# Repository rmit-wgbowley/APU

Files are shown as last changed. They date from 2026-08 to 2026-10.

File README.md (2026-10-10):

<!--
Colors:
FFFFFF - Pure white
e01e37 - Bold crimson-red 

Hello,
I enjoyed working with others for once, and being able
to have my own architecturally defined piece in the 
car is pretty damn cool.

- William Bowley, 2026-08-17

P.S: 
Thanks for downloading the APU repository `▽`ʃ♡ — but please be safe with high-voltage boards :)

-->

<div align="center">
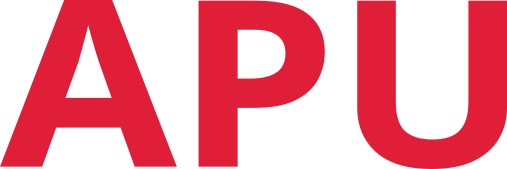
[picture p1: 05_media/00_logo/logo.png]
APU Logo
  

  A proposed low-voltage grounded APU for FSAE-A vehicles <br>
</div>

### Overview

The APU is a proposed power architecture that allows the tractive battery, while connected, to feed the low-voltage grounded (LVG) system via an isolated LLC converter, using the LVG battery as a line buffer. 
The LVG battery also allows for standby mode while the tractive battery is disconnected.

```
Traction battery (600 V) → APU-LLC (12 V) → APU-Battery (12 V) → LVG Systems (12 V)
```

### Objectives

```
- [/] Support a `400-600 V` input range from the tractive battery.
- [/] Support up to `300 W (DC)` continuous loads and `800 W (DC)` peak transient loading.
- [/] Reach an asymptote temperature under `70°C` with passive cooling.
- [ ] Validate the APU architecture and generate performance curves.
- [ ] Pass the EMC/EMI requirements and pass the 2027 Formula SAE rules inspection.
```

> *(Note). `[ ]` Not started. `[/]` In progress. `[x]` Complete.*

---

### Magnetic Passives

> *(Ordered). The transformer and inductor formers and cores are on-hand, with litz wire yet to be ordered.*

#### Transformer

The transformer used for this design has an `N87` core with a `glass fibre` coil former and snap-on `ABS` insulation rings. 
The turns ratio is `21:1:1`, with `0.125 mm × 64` litz wire used on the primary with a PTFE sleeve across 3 layers of 14 turns each. 
The secondary and tertiary windings each have a single layer of 2 turns with `0.125 mm × 650` litz wire. Each layer is wrapped in `0.1 mm`
polyimide tape.

<div align="center">
  <table>
    <tr>
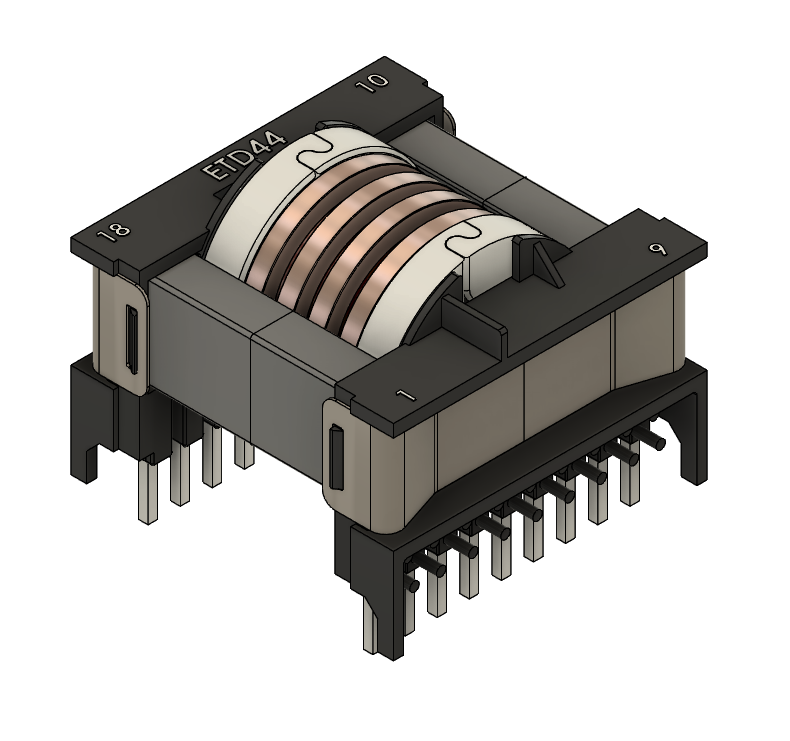
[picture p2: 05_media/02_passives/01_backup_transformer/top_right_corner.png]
Transformer 2 Side
      <td></td>
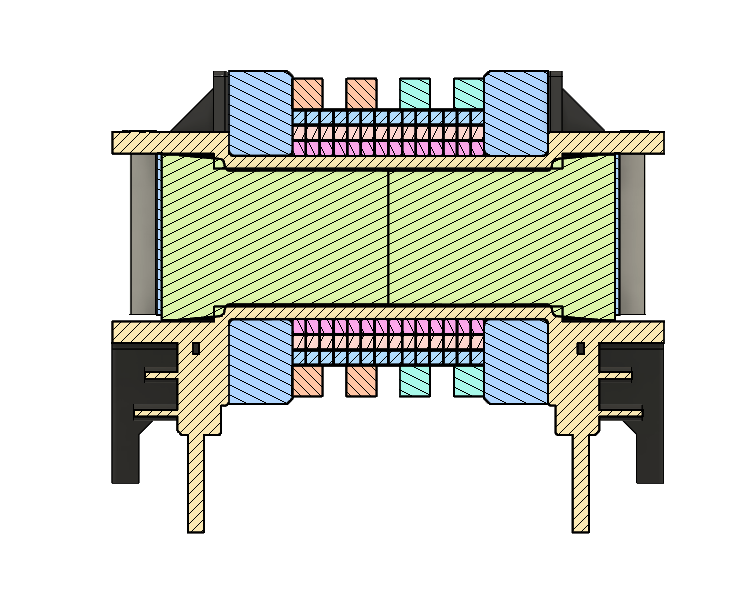
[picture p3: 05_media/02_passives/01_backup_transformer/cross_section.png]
Transformer 2 Cross Section
      <td></td>
    </tr>
  </table>
</div>

#### External Inductor

The external inductor used for this design has an `N87` core with a `glass fibre` coil former, and uses the same litz wire (`0.125 mm × 64`) as the transformer primary. The number of turns within the inductor is dependent on the transformer's characteristics.

<div align="center">
  <table>
    <tr>
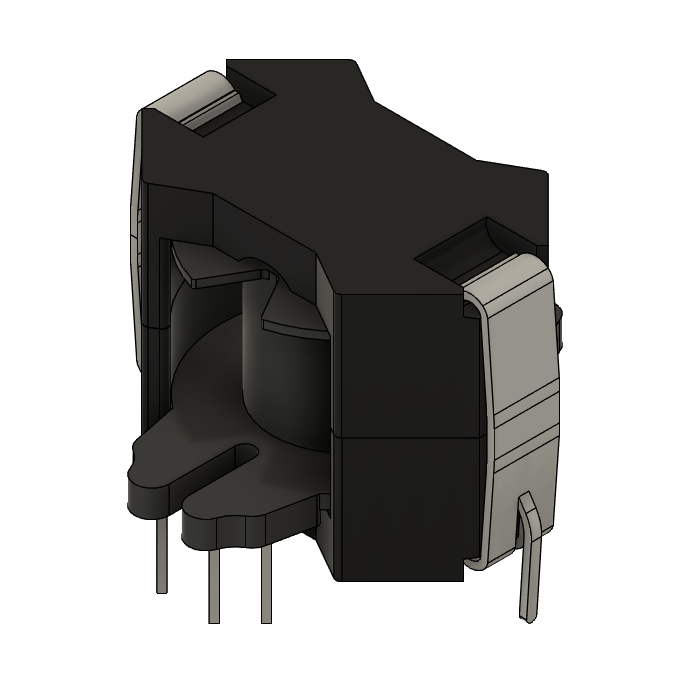
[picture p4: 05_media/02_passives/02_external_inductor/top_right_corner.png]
External Inductor Side
      <td></td>
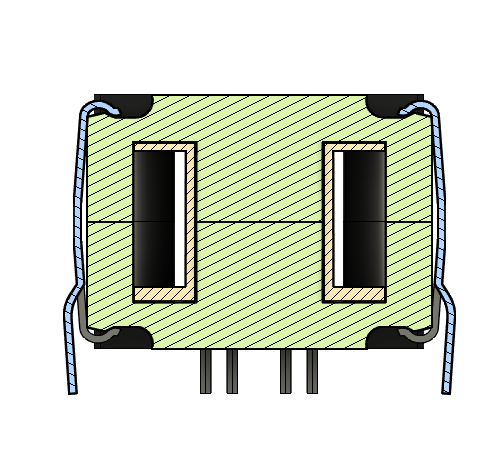
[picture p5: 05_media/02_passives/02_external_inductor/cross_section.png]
External Inductor Cross Section
      <td></td>
    </tr>
  </table>
</div>

See the [`02_passives`](./02_passives/readme.md) for implementation details.

---

### LLC Boards

#### LLC High Voltage Side (LLC-HVS)

> *(Work in progress). This board is currently being designed in altium*

This board uses the `UCC25600DRG4` resonant mode controller to control the LLC half-bridge via the `ISO7720DWVR` for digital isolation. The half-bridge itself is built around the `IR2214SSPBF` with two `E3M0075120K` FETs. This board also contains the resonant network and the primary side of the transformer.

```
Resonant Controller (UCC25600DRG4)
              ↓
Digital Isolator (ISO7720DWVR)
              ↓
Half Bridge Driver (IR2214SSPBF) → FETs (E3M0075120K)
              ↓
Resonant Network (Series Capacitor, Inductor & Transformer Primary)
```

#### LLC Low Voltage Side (LLC-LVS)

> *(Dependency). This board is currently paused until the LLC-HVS is finished.*

See the [`03_boards`](./03_boards/readme.md) for implementation details.

---

### APU Battery & External Charging Interface

> *(Dependency). The APU battery is dependent on the implementation of the LLC-HVS and LLC-LVS.*

The proposed battery type for the APU battery is a soft-case LiPo using cells in series to achieve the required 12 V. 
LiPo batteries also tend to have a high C-rating, hence they can buffer high line transients.

---

### APU Packaging & Integration

> *(Dependency). The APU packaging is dependent on all of the above.* <br>

The proposed integration is to package the LLC converter above the APU battery, with the converter ultimately sitting next to the 
APU-BI and APU-EBC boards, with a separation plane between the battery.

---

### Documentation

Each section of the repo is self-documenting. <br>
For internal documentation, credits, and contributors, refer to [`00_docs`](./00_docs/readme.md).

---

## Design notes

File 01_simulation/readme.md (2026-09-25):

### Overview

This folder contains the simulation workflows used within this project, including finite element analysis, 
analytical modelling, and circuit-net (SPICE) simulations.

---

### 00_analytical

This folder contains analytical models for exploring design variables and building system intuition at medium fidelity but extremely fast.

```
- First Harmonic Approximation (FHA)
- Transfer Gain vs Input Voltage
- Winding Loading
```

For detailed documentation, refer to [`00_analytical/readme.md`](00_analytical/readme.md).

---

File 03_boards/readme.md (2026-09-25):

### 03_boards

This folder contains the board designs for the LLC converter, external battery charger interface, and battery connector interface.

---

### [00_LLC_HVS](./00_llc_hvs/readme.md)

LLC High Voltage Side

*(TBD) — Work in progress*

---

### [01_LLC_LVS](./01_llc_lvs/readme.md)

LLC Low Voltage Side

*(TBD) — Work in progress*

---

### 02_APU_EBC

Auxiliary Power Unit External Battery Charger

*(TBD) — Work in progress*

---

### 03_APU_BI

Auxiliary Power Unit Battery Interface

*(TBD) — Work in progress*

---

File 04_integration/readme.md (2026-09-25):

### 04_integration

This folder contains the packaging for the LLC converter, battery interface components and the battery.

*(TBD) — Work in progress*

---

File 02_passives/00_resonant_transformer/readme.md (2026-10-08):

### 00_resonant_transformer

Both resonant transformers use an `N87` core with a `glass fibre` coil former and snap-on `ABS` insulation rings. The turns ratio is `21:1:1`, with `0.125 mm × 64` litz wire used on the primary with PTFE sleeve across 3 layers of 14 turns each. The secondary and tertiary windings each have a single layer of 2 turns with `0.125 mm × 650` litz wire. Each layer is wrapped in `0.1 mm` polyimide tape.

#### Primary Transformer

<div align="center">
  <table>
    <tr>
      <td>Transformer 2 Side</td>
      <td>Transformer 2 Cross Section</td>
    </tr>
  </table>
</div>

The primary transformer uses the `B66364A2000X000` core and `B66363G0000X187` coil former. 
This transformer has a smaller cross-sectional area than the backup transformer, which means it saturates at a lower current.

---

#### Backup Transformer

<div align="center">
  <table>
    <tr>
      <td>Transformer 2 Side</td>
      <td>Transformer 2 Cross Section</td>
    </tr>
  </table>
</div>

The backup transformer uses the `B66366A2000X000` core and `B66365G0000X187` coil former. 
This transformer has a larger cross-sectional area than the primary, which means it saturates at a higher current.

---

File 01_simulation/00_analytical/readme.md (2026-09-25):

### 00_analytical

This folder contains analytical models to explore design variables at medium fidelity but extremely fast.

> Do not assume the resulting design variables are suitable for fabrication or real-world use without further analysis.

#### First Harmonic Approximation (FHA)

This analytical model is written in `Python` and uses `picounits` for parameter loading and unit validation. It models the resonant circuit two-port model described in application note `AN2450` by ST,
and also in a `2024 RMIT` paper, though they use different models. The ST FHA model was used in this implementation.

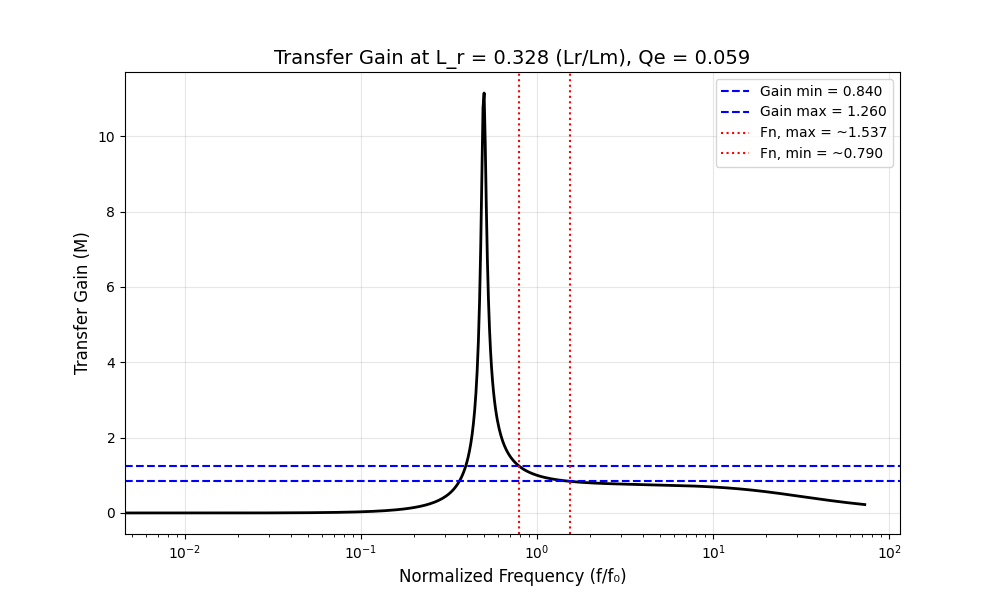
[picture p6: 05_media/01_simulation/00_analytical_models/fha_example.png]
FHA_Example
<div align="center">
<p><em>Figure 1: First Harmonic Approximation output showing transfer gain (linear) vs frequency (log).</em></p></div>

> Model: [`first_harmonic_approximation`](./00_first_harmonic_approximation/main.py)  
> Parameters: [`parameters.uiv`](./00_first_harmonic_approximation/parameters.uiv)

---

#### Transfer Gain vs Input Voltage

This analytical model is written in `Python` and uses `picounits` for parameter loading and unit validation. It models the 
transfer gain vs input voltage using the equations described in application note `AN2450` by ST.

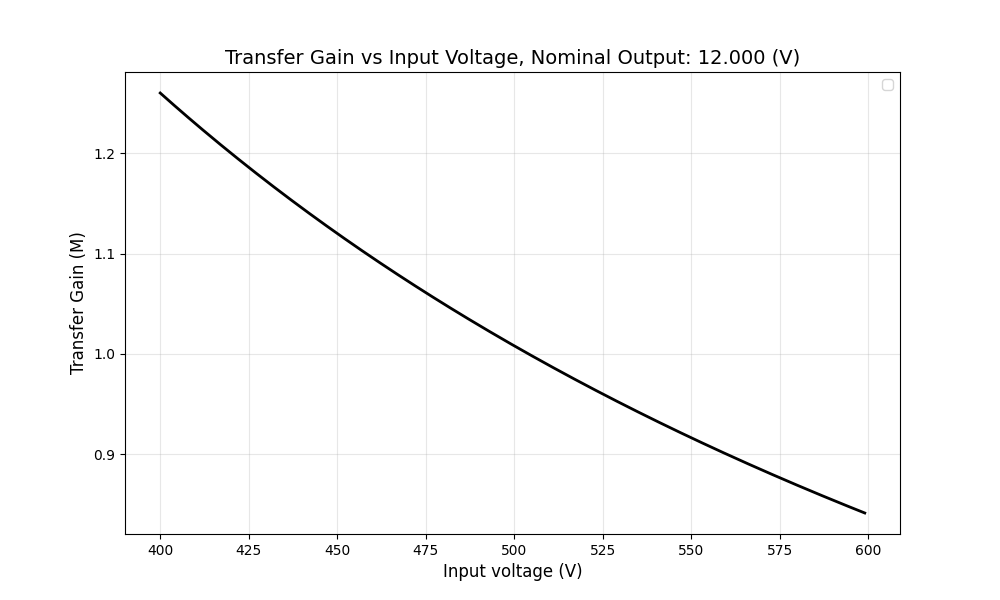
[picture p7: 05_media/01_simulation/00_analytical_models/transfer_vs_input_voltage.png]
Transfer gain vs input voltage
<div align="center">
<p><em>Figure 2: Analytical model showing transfer gain (linear) vs input voltage (linear).</em></p></div>

> Model: [`transfer_gain`](./01_transfer_gain/main.py)  
> Parameters: [`parameters.uiv`]`(./01_transfer_gain/parameters.uiv)

---

#### Winding Loading

This analytical model is written in `Python` and uses `picounits` for parameter loading and unit validation. It calculates primary and secondary wire diameters across a range of current densities at a target power level, helping to inform winding design for the LLC converter.

> Wire diameters shown are bulk equivalents. Litz wire or multi-strand conductors are required in practice due to skin effect at high frequencies.

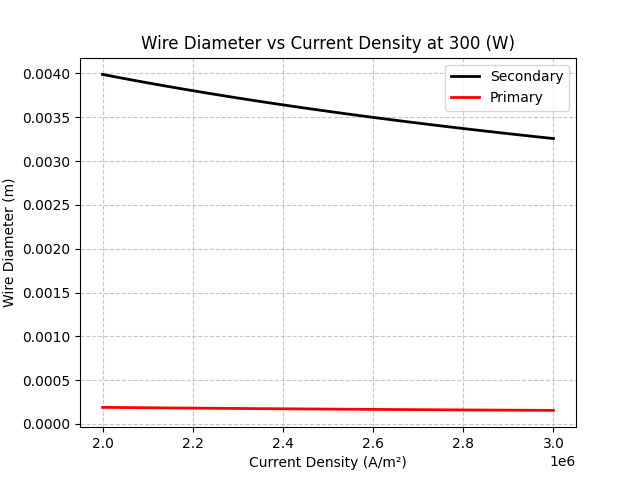
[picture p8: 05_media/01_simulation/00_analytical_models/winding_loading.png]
Winding loading analysis
<div align="center">
<p><em>Figure 3: Primary and secondary wire diameter vs current density at a fixed target power.</em></p></div>

> Model: [`winding_load`](./02_winding_loading/main.py)  
> Parameters: [`parameters.uiv`](./02_winding_load/parameters.uiv)

---

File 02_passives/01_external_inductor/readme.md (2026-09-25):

### 01_external_inductor

The external inductor uses the `B65811J0400A087` core with a `B65812N1012D001` coil former and `0.125 mm × 64` litz wire used on the primary with a PTFE sleeve.

<div align="center">
  <table>
    <tr>
      <td>External Inductor Side</td>
      <td>External Inductor Cross Section</td>
    </tr>
  </table>
</div>

---

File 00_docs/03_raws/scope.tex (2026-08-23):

\documentclass[12pt,a4paper]{article}
\usepackage[utf8]{inputenc}
\usepackage{geometry}
\geometry{margin=1in}
\usepackage{graphicx}
\usepackage{float}        
\usepackage{titlesec}
\usepackage{tocloft}
\usepackage{hyperref}
\usepackage{fancyhdr}
\usepackage{textcomp} 
\usepackage{listings}

\lstset{
    frame=single,
    basicstyle={\small\ttfamily},
    breaklines=true,
    columns=flexible,
    literate={->}{{ $\rightarrow$} }2
             {<-}{{$\leftarrow$} }2
             {down}{{$\downarrow$}}4
}

\hypersetup{
    colorlinks=true,
    linkcolor=blue,
    urlcolor=blue,
}

% Customize section formatting
\titleformat{\section}{\large\bfseries}{\thesection}{1em}{}
\titleformat{\subsection}{\normalsize\bfseries}{\thesubsection}{1em}{}

% Header and footer setup
\pagestyle{fancy}
\fancyhf{}

% Left header
\fancyhead[L]{\textbf{Project Scope}}

% Right header
\fancyhead[R]{\textbf{LVG-APU}}

% Page number in footer
\fancyfoot[C]{\thepage}

\begin{document}

% Title Page
\begin{center}
    {\Large \textbf{Low Voltage Grounded Auxiliary Power Unit}} \\[0.3cm]
    {\large AUTO1931 | Project Scope Report} \\[0.2cm]
    {\today}\\[0.5cm]
\end{center}

\vfill

% ========== Overview ==========
\section*{Overview}

Formula SAE Electric (FSAE-E) vehicles have two main voltage levels: one is the tractive system, which is up to 600 VDC, and the
other is the low-voltage grounded (LVG) system, which is up to 60 VDC. RMIT Motorsports (RMIT-M) uses a 600 V tractive system and a 13.2 V LVG system.
The tractive system is supplied by the tractive battery, which contains 143 lithium cells. Similarly, the LVG system is supplied by a lithium battery.
However, it is a commercial unit certified by the FAA for aircraft!?

\vspace{0.5cm}

The low-voltage grounded auxiliary power unit (APU) is a proposed design to feed the LVG system from the tractive system while the tractive battery
is installed in the vehicle. This APU would also have to be able to supply power while the tractive battery is disconnected from the vehicle, so it is
also proposed that the LVG battery is scoped within the component. Hence the name ``auxiliary power unit,'' as it provides the power required (LVG battery)
during setup to close the contactor (similar to cranking amps), which is required to power the isolated (split grounds) DC-to-DC converter.

\vspace{0.5cm}

Later, the LVG battery buffers the line voltage during heavy loading, reducing the converter's required power output range. This also allows for the
implementation of isolated external power input for the LVG battery, which is proposed to be an IP-rated (ingress protection) USB-C input to remove the 
dependency of another charging apparatus within the vehicle supporting equipment. This allows for a design with high self-reliance. At worst, it could be a USB-C laptop charger!

\vspace{0.5cm}

\begin{quote}
  \textbf{Supporting:}
    The impedance (L, R) between the LVG battery and the DC-to-DC converter is important due to the coupling (mutual influence) between them when supplying the 
    line voltage across a wide range of power draws and rates of change of that draw. Hence the inclusion.
\end{quote}

\newpage

% ========== System Specifications ==========
\section{System Specification}

The APU as an intermediate component between the tractive system and the LVG system, is designed from the interfaces inwards (within reason). Hence the first specification 
is the input voltage range, which can be derived from the voltage cycle of a single lithium battery. The average rating is \~3.7 V, the maximum is \~4.2 V, and the minimum is \~3.0 V, with 
approximately 143 cells within the tractive battery. The input voltage range is \~600--400 V, whereas the output, for simplicity, will be \~12 V.

\vspace{0.5cm}

This leads into the power requirements, which is quite a complex question to answer in any capacity other than building and measuring the R27 LVG system. However, the R26 design can be used as a 
reference for this. According to an approximate current draw diagram, the LVG system should draw 15.9 A continuously with a peak of 66 A (Appendix 1a). This translates to a power output range of 
\~190--790 W.

\begin{quote}
  \textbf{Supporting:} 
  It should be noted that the exact technique used to approximate these values is unknown, and a few items are poorly defined.
\end{quote}

The two topologies that were assessed were a flyback converter and an LLC converter. A flyback works by storing energy in the magnetic field of a transformer and then releasing it in pulses. This allows 
for the output voltage to be controlled at a high level by the duration of the repeating ``on'' pulse (PWM). The LLC converter uses a switching configuration to generate a square wave, and then that wave enters 
a resonant tank, which is simply a capacitor and inductor in series or parallel. This tank produces a sinusoidal wave and, like the flyback, has a transformer which then outputs the energy (at a high level). 
The output can then be controlled through the switching signal by varying frequency and timing.

\vspace{0.5cm}

From those two topologies, the main cornerstone for selecting one is the power output required rather than specifically implementation complexity. From this perspective, the LLC is preferable as it often has better 
scaling capabilities. Since it is not storing energy in pulses, the maximum output range can be much higher. The LLC also has two different methods of controlling the output, each of which has different power ranges. 
This allows for more implementation options on top (half-bridge vs. full-bridge). Hence, the LLC topology was chosen.

\vspace{0.5cm}

Therefore, the LLC converter will need to be sized for the approximate nominal power draw and acceptable current density within the LLC transformer. Using a rule-of-thumb model (Appendix 1b) based on current density and 
wire diameter, a series of graphs relating current density and wire diameter were generated. From that and the power range inherited by the R26 documentation and R\&D report about future driverless integration, a 
final requirement of 300 W was decided. It should allow up to 33\% output buffer based on R26 continuous draw, while also not making the transformer impractical to design.

\begin{quote}
  \textbf{Rationale:} 
  At a current density (current per cross-sectional area) of $\sim 2.6 \, {A/mm}^2$ on the secondary with a ratio from an RMIT-M paper of 21:1, a bulk (solid) diameter of 3.5 mm is required, which is reasonable. 
  It falls within the natural cooling range at 2.0--3.0 ${A/mm}^2$ and insulation class A, which is abundant.
\end{quote}

% ========== Literature and Design Review ==========
\section{Literature and Design Review}

The search performed during this scoping phase did not identify the APU as an established discrete system architecture. Therefore, the review focuses on the isolated
LLC converter, which forms the centre of gravity of the proposed architecture.

\begin{lstlisting}
Traction battery (600 V)
        down
LVG-APU Input Interface
-----------------------------------------------------------------
Isolated LLC resonant DC/DC (300 W Target) <- (We're Here)
        down
LV battery buffer (Energy Buffer) <- Isolated Charger (External Input)
-----------------------------------------------------------------
LVG-APU Output Interface
        down
LV vehicle systems (12 V) (200 W Estimate)
\end{lstlisting}

\begin{quote}
  \textbf{Important:} 
    We're here! Given the initial scoping of ``600V to 12V Isolated DC/DC Converter \& LV Integration,'' the above analysis had to be done to decompose and reconstruct the 
    system for clear design and objectives.
\end{quote}

\subsection{A Customised Low-voltage Power Supply for a Formula SAE Electric Racing Vehicle}

This paper is relevant as it describes the design and implementation of a 240 W LLC converter for FSAE and was completed in 2024 by RMIT-M students for a capstone.
This design implements the LLC converter as a single package consisting of five different boards following a modular approach. The switching method is a half-bridge
and gate driver, which is then controlled by a resonant controller. The switches were 1200 V silicon carbide FETs, and the frequency range was 100--200 kHz with a
21:1 turn ratio within the transformer and series capacitor. The output is then filtered by a synchronous rectifier.

\begin{figure}[H]
    \centering
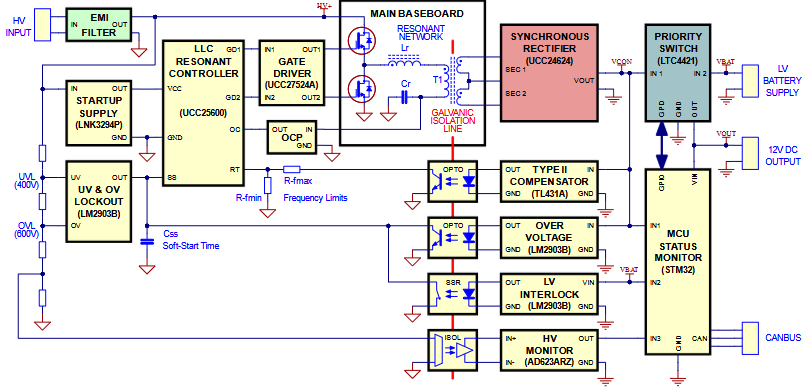
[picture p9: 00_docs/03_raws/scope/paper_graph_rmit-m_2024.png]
    
    \caption{Block diagram of the LLC converter from the paper}
\end{figure}

\subsection{DCDC: An open source credit card sized DC/DC converter to convert up to 600 V to 24 V in an energy-, cost- and space-efficient way}

This repository (repo) contains a high-voltage DC/DC converter designed for the FSAE German competition and, according to the repo, passed 
scrutineering twice and has been operating without issues for over 6 months. The maximum output power is 750 W for 60 seconds and 500 W continuous. The
design input voltage range is 200 to 600 V and has an output range of 24 V, with the ability to customize it for 12 V to 48 V outputs. The design
is quite small at only 167 grams and has a volume of 0.208 L. 

\begin{figure}[H]
    \centering
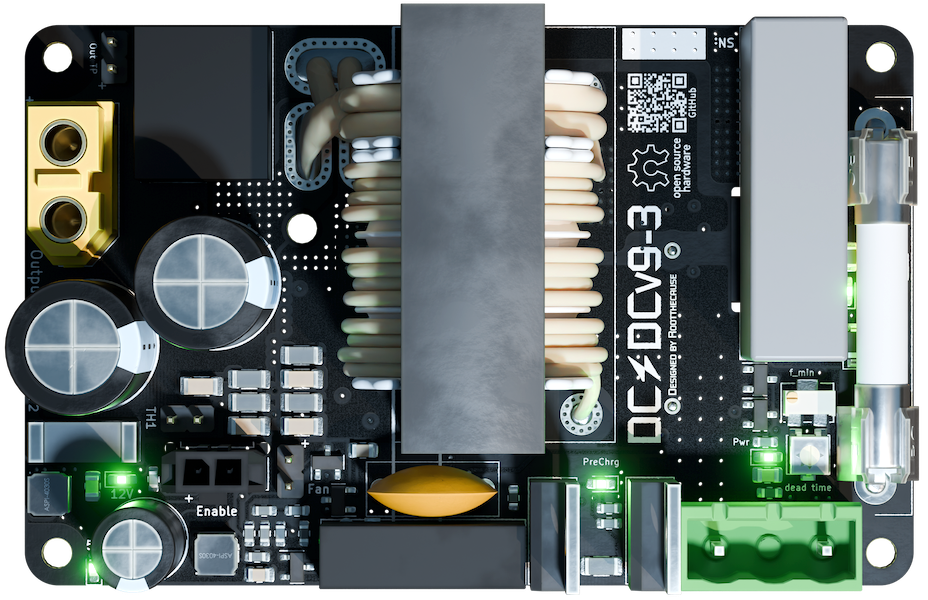
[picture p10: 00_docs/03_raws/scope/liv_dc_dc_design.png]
    
    \caption{DC/DC PCB design populated with components}
\end{figure}

According to the repo, the design features a solid-state precharge circuit, active rectification, and under- and over-voltage protection. It also
has over-current protection and, lastly, HV and LV fuses. The repo notes that the dynamic operating range is 90 to 200 kHz to ``ensure high efficiency for various loads''
and ``good EMI compliance due to \ldots LLC topology.''

\subsection{Interpretation}

The two reviewed designs demonstrate that isolated LLC conversion is an established approach for high-voltage to low-voltage conversion. Both operate over an input 
range overlapping with the 400--600 V requirement, while their power ratings of 240 W and 600 W provide precedent for the 300 W target.

\vspace{0.5cm}

However, neither design directly establishes the proposed APU architecture. The reviewed systems seem to treat the DC/DC converter as the power-supply 
component in abstract rather than as a coupled system. Therefore, these designs will be used as precedent for the LLC subsystem rather than as a complete implementation
reference.

\vspace{0.5cm}

The 2024 RMIT-M paper will be the primary reference for the LLC converter design and implementation, as it shows the design methodology for designing the system using
first harmonic approximation (FHA) and detailed transformer construction methods. The modular design approach is quite elegant from a testing perspective. Hence, a similar approach
will be adopted for this implementation.

% ========== Conceptual Design ==========
\section{Conceptual Design}

The proposed design for the APU is to begin with the LLC converter as two independent boards, which are then mechanically and electrically connected
via the high-frequency transformer. This reflects the natural system boundaries between the high and low voltage sides while also improving the ability to perform
sub-circuit testing following a similar approach to the 2024 RMIT-M paper.

\vspace{0.5cm}

\hbox{\large{High Level Topology:}}
\begin{lstlisting}
Interface (Undecided Connector) 
LLC-HV - Tractive battery input (400-600V domain) (Unknown EMI)
-----------------------------------------------------------------
EMI filter (Common-mode chokes) (Shunt Capacitors)
        down
Half Bridge Mosfets <- Half bridge Driver IC <- LLC Controller <- Optocoupler
        down
Resonant Tank Circuit
-----------------------------------------------------------------
High Frequency Transformer (Primary) (400-600 HF AC)

=============================================
Ferrite Core (Magnetic & Structural Coupling)
=============================================

LLC-LV - High Frequency transformer (Secondary) (12V AC) (Unknown Ripple)
-----------------------------------------------------------------
Synchronous Rectifier -> Status MCU (STM32) <- Optocoupler
        down
Integrated battery (12 V) (Undecided Capacity) <- Isolated Charger
-----------------------------------------------------------------
LV-Interface (Undecided Connector) (12V Domain) (Unknown EMI)
\end{lstlisting}

\vspace{0.5cm}

This design follows the 2027 Formula SAE rules draft. It allows for a GLV system to operate independently of the tractive battery (EV.4.4.1). It also
is galvanically isolated via magnetic coupling and optocouplers for signal routing (EV.7.5.1). It also avoids the same-board tractive system and GLV rule (EV.7.5.7) 
with two independent boards. However, for the optocouplers on the LLC-HV board, the area will be clearly marked and have a clearance distance of 3.0 mm and a creepage distance under
conformal coating of 4.0 mm when operating at 300--600 VDC (EV 7.5.7).

\vspace{0.5cm}

The implementation plan is firstly to use planar finite element analysis to design the ferrite core transformer, and then design the LLC-HV board. The transformer will then be characterized,
and an appropriate capacitor will be chosen. Then the LLC-HV board and transformer will be tested together with a dummy load. After that, the LLC-LV board will be made based on those testing
results. The LLC-HV and LLC-LV boards will then be tested together and characterized, with the transient response helping to determine the capability of the APU-integrated battery. After which,
the whole system will be packaged together as the LVG-APU and tested for EMI compliance, etc.

\vspace{0.5cm}

%========== Project Management ==========
\section{Project Management}

The project will follow a waterfall-like project cycle, with each deliverable design leading into the next (within reason). The project deliverables consist of the LLC-HV and LLC-LV boards, the 
transformer, the LVG battery, and finally the APU package around those components.

\begin{figure}[H]
    \centering
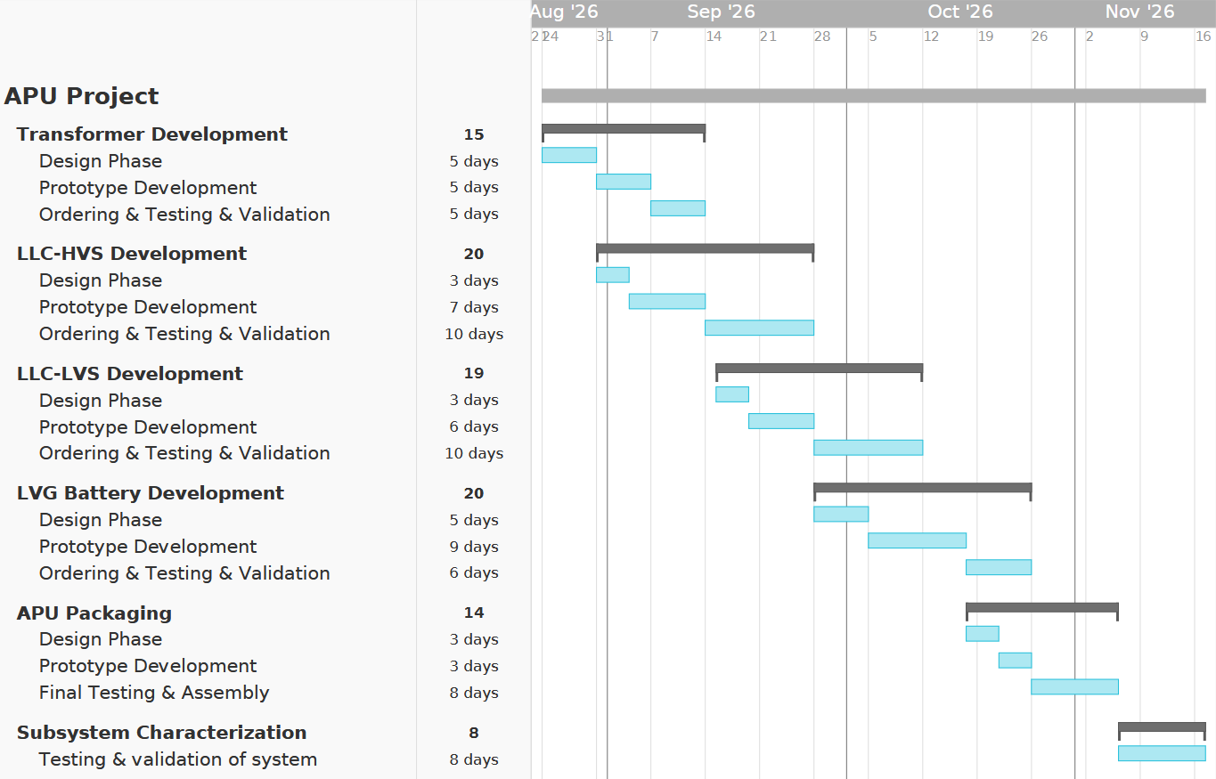
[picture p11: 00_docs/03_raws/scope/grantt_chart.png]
    
    \caption{Gantt chart showing the project timeline and deliverables}
\end{figure}

\begin{quote}
  \textbf{Rationale:} 
  The deliverables overlap, as the design phase of each defines enough information to begin development of the next. Given the timeframe of this project, 
  the execution has to be concurrent. The ``Ordering \& Testing \& Validation'' blocks are due to the transient nature of procurement and safety reviews.
\end{quote}

\vspace{0.5cm}

Similar to the project scope phase, the implementation work will be hosted on GitHub with code, documentation, and reference implementation within the repo.
Engineering notes and design rationale will be within the repo issues. The repo follows the information scheme for issues (Appendix 2).

% ========== Conclusion ==========
\section{Conclusion}

The LVG-APU for the R27 vehicle will be a first iteration of a new power system within the vehicle. The design arises from the architectural requirements 
of the LVG system, and the requirements formed arise from the current implementation and reference designs described in the literature review. The system consists of five deliverables:
the LLC-HV and LLC-LV boards, the transformer, the LVG battery, and the APU packaging.

% ========== References ==========
\section{References}

\begin{enumerate}
    \item RMIT Motorsports, ``A Customised Low-voltage Power Supply for a Formula SAE Electric Racing Vehicle'', Capstone Project, RMIT University, 2024.
    \item RMIT Motorsports, ``Innovative Actuation Systems for a Driverless Formula SAE Racing Car'', Capstone Project, RMIT University, 2021.
    \item liv (rootthecause), ``DCDC: An open source credit card sized DC/DC converter to convert up to 600 V to 24 V in an energy-, cost- and space-efficient way'',
    GitHub repository. Available: https://github.com/liv-instruments/dcdc
    \item Formula SAE Rules, ``2027 Formula SAE Rules'', SAE International, Draft, 2026.
\end{enumerate}

% ========== Appendices ==========
\section{Appendices}

\subsection{Appendix 1a: R26 LVG System Current Draw Estimation}

\begin{figure}[H]
    \centering
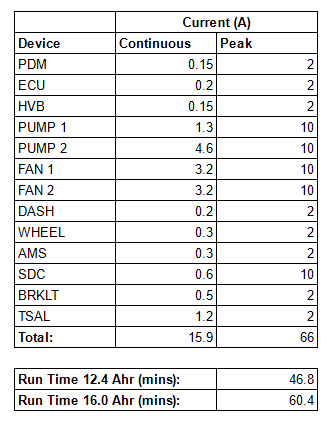
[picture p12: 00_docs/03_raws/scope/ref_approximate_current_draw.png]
    
    \caption{R26 LVG System Current Estimation}
\end{figure}

\newpage

\subsection{Appendix 1b: Current Density and Wire Diameter Model}

\begin{lstlisting}
# Calculate wire diameter across current density range at target power
current_density = parameters.transformer.range.min_current_density
while current_density <= parameters.transformer.range.max_current_density:
    # Calculates the wire diameter based on target current & current density
    inner_term = 4 * target_current / (pi * current_density)
    secondary_wire_diameter = inner_term ** 0.5
    primary_wire_diameter = secondary_wire_diameter / parameters.transformer.turns

    # Saves parameters as raw values (kA/m^2, mm, mm)
    current_density_axis.append(current_density.stripped * 10 ** -3)
    primary_wire_diameter_axis.append(primary_wire_diameter.stripped * 10 ** 3)
    secondary_wire_diameter_axis.append(secondary_wire_diameter.stripped * 10 ** 3)

    # Updates current density for next iteration
    current_density += parameters.numerics.current_density
\end{lstlisting}

\subsection{Appendix 2: GitHub Issue Labelling Scheme}

\begin{lstlisting}
LX -> Documentation and project structure
L0 -> Review and analysis of reference designs
L1 -> System level design, topology and interfaces
L2 -> Detailed design & prototyping
L3 -> Testing & Validation of prototype
DS -> De-scoped Feature, De-scoped Analysis
AC -> Architectural Change
\end{lstlisting}

\end{document}

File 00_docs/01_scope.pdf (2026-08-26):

Project Scope | LVG-APU

## Low Voltage Grounded Auxiliary Power Unit

### AUTO1931 — Project Scope Report

August 26, 2026

### Overview

Formula SAE Electric (FSAE-E) vehicles have two main voltage levels: one is the tractive system, which is up to 600 VDC, and the other is the low-voltage grounded (LVG) system, which is up to 60 VDC. RMIT Motorsports (RMIT-M) uses a 600 V tractive system and a 13.2 V LVG system. The tractive system is supplied by the tractive battery, which contains 143 lithium cells. Similarly, the LVG system is supplied by a lithium battery. However, it is a commercial unit certified by the FAA for aircraft!?

The low-voltage grounded auxiliary power unit (APU) is a proposed design to feed the LVG system from the tractive system while the tractive battery is installed in the vehicle. This APU would also have to be able to supply power while the tractive battery is disconnected from the vehicle, so it is also proposed that the LVG battery is scoped within the component. Hence the name “auxiliary power unit,” as it provides the power required (LVG battery) during setup to close the contactor (similar to cranking amps), which is required to power the isolated (split grounds) DC-to-DC converter.

Later, the LVG battery buffers the line voltage during heavy loading, reducing the converter’s required power output range. This also allows for the implementation of isolated external power input for the LVG battery, which is proposed to be an IP-rated (ingress protection) USB-C input to remove the dependency of another charging apparatus within the vehicle supporting equipment. This allows for a design with high self-reliance. At worst, it could be a USB-C laptop charger!

Supporting: The impedance (L, R) between the LVG battery and the DCto-DC converter is important due to the coupling (mutual influence) between them when supplying the line voltage across a wide range of power draws and rates of change of that draw. Hence the inclusion.

### 1 System Specification

The APU as an intermediate component between the tractive system and the LVG system, is designed from the interfaces inwards (within reason). Hence the first specification is the input voltage range, which can be derived from the voltage cycle of a single lithium battery. The average rating is ˜3.7 V, the maximum is ˜4.2 V, and the minimum is ˜3.0 V, with approximately 143 cells within the tractive battery. The input voltage range is ˜600–400 V, whereas the output, for simplicity, will be ˜12 V.

This leads into the power requirements, which is quite a complex question to answer in any capacity other than building and measuring the R27 LVG system. However, the R26 design can be used as a reference for this. According to an approximate current draw diagram, the LVG system should draw 15.9 A continuously with a peak of 66 A (Appendix 1a). This translates to a power output range of ˜190–790 W.

Supporting: It should be noted that the exact technique used to approximate these values is unknown, and a few items are poorly defined.

The two topologies that were assessed were a flyback converter and an LLC converter. A flyback works by storing energy in the magnetic field of a transformer and then releasing it in pulses. This allows for the output voltage to be controlled at a high level by the duration of the repeating “on” pulse (PWM). The LLC converter uses a switching configuration to generate a square wave, and then that wave enters a resonant tank, which is simply a capacitor and inductor in series or parallel. This tank produces a sinusoidal wave and, like the flyback, has a transformer which then outputs the energy (at a high level). The output can then be controlled through the switching signal by varying frequency and timing.

From those two topologies, the main cornerstone for selecting one is the power output required rather than specifically implementation complexity. From this perspective, the LLC is preferable as it often has better scaling capabilities. Since it is not storing energy in pulses, the maximum output range can be much higher. The LLC also has two different methods of controlling the output, each of which has different power ranges. This allows for more implementation options on top (half-bridge vs. full-bridge). Hence, the LLC topology was chosen.

Therefore, the LLC converter will need to be sized for the approximate nominal power draw and acceptable current density within the LLC transformer. Using a rule-of-thumb model (Appendix 1b) based on current density and wire diameter, a series of graphs relating current density and wire diameter were generated. From that and the power range inherited by the R26 documentation and R&D report about future driverless integration, a final requirement of 300 W was decided. It should allow up to 33% output buffer based on R26 continuous draw, while also not making the transformer impractical to design.

Rationale: At a current density (current per cross-sectional area) of ∼
2.6 A/mm²
on the secondary with a ratio from an RMIT-M paper of 21:1, a bulk (solid) diameter of 3.5 mm is required, which is reasonable. It falls within the natural cooling range at 2.0–3.0 A/mm²
and insulation class A,
which is abundant.

### 2 Literature and Design Review

The search performed during this scoping phase did not identify the APU as an established discrete system architecture. Therefore, the review focuses on the isolated LLC converter, which forms the centre of gravity of the proposed architecture.

Traction battery (600 V)
↓
LVG-APU Input Interface
-----------------------------------------------------------------Isolated LLC resonant DC/DC (300 W Target) ← (We’re Here)
↓
LV battery buffer (Energy Buffer) ← Isolated Charger (External Input) -----------------------------------------------------------------LVG-APU Output Interface
↓
LV vehicle systems (12 V) (200 W Estimate)

Important: We’re here! Given the initial scoping of “600V to 12V Isolated DC/DC Converter & LV Integration,” the above analysis had to be done to decompose and reconstruct the system for clear design and objectives.

### 2.1 A Customised Low-voltage Power Supply for a Formula SAE Electric

Racing Vehicle

This paper is relevant as it describes the design and implementation of a 240 W LLC converter for FSAE and was completed in 2024 by RMIT-M students for a capstone. This design implements the LLC converter as a single package consisting of five different boards following a modular approach. The switching method is a half-bridge and gate driver, which is then controlled by a resonant controller. The switches were 1200 V silicon carbide FETs, and the frequency range was 100–200 kHz with a 21:1 turn ratio within the transformer and series capacitor. The output is then filtered by a synchronous rectifier.

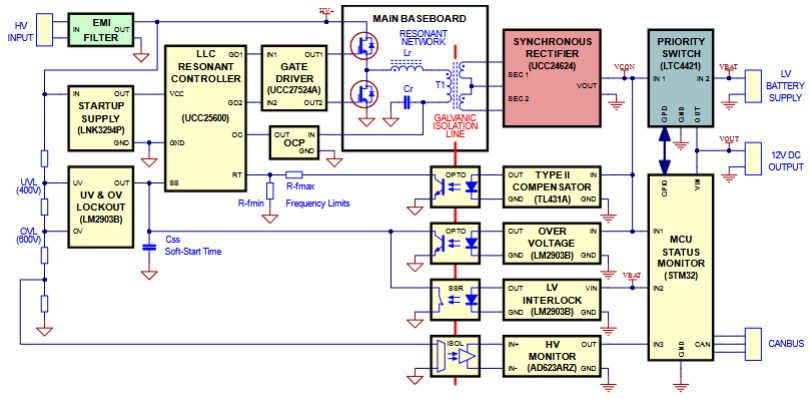
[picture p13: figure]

Figure 1: Block diagram of the LLC converter from the paper

### 2.2 DCDC: An open source credit card sized DC/DC converter to convert

up to 600 V to 24 V in an energy-, cost- and space-efficient way

This repository (repo) contains a high-voltage DC/DC converter designed for the FSAE German competition and, according to the repo, passed scrutineering twice and has been operating without issues for over 6 months. The maximum output power is 750 W for 60 seconds and 500 W continuous. The design input voltage range is 200 to 600 V and has an output range of 24 V, with the ability to customize it for 12 V to 48 V outputs. The design is quite small at only 167 grams and has a volume of 0.208 L.

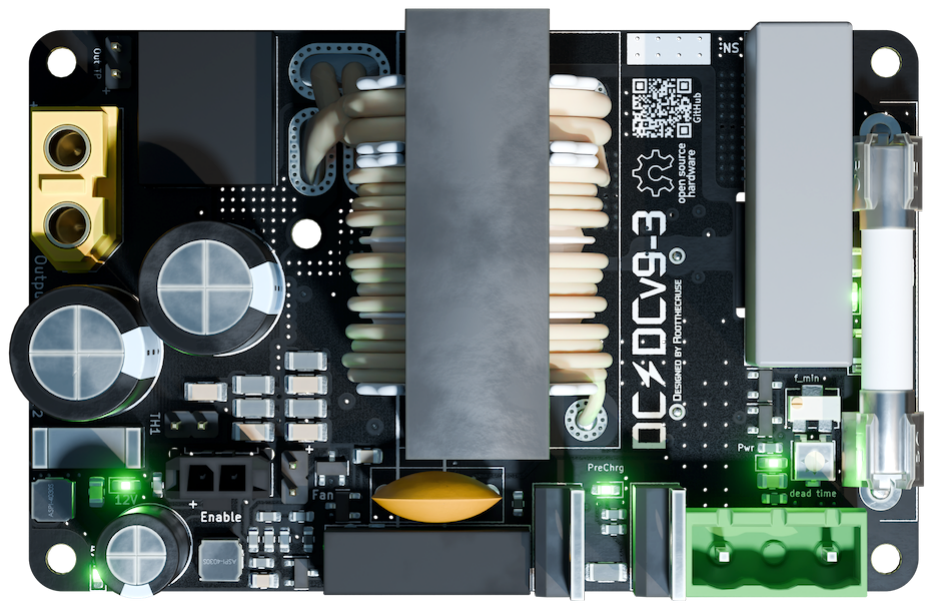
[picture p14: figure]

Figure 2: DC/DC PCB design populated with components

According to the repo, the design features a solid-state precharge circuit, active rectification, and under- and over-voltage protection. It also has over-current protection and, lastly, HV and LV fuses. The repo notes that the dynamic operating range is 90 to 200 kHz to “ensure high efficiency for various loads” and “good EMI compliance due to . . . LLC topology.”

### 2.3 Interpretation

The two reviewed designs demonstrate that isolated LLC conversion is an established approach for high-voltage to low-voltage conversion. Both operate over an input range overlapping with the 400–600 V requirement, while their power ratings of 240 W and 600 W provide precedent for the 300 W target.

However, neither design directly establishes the proposed APU architecture. The reviewed systems seem to treat the DC/DC converter as the power-supply component in abstract rather than as a coupled system. Therefore, these designs will be used as precedent for the LLC subsystem rather than as a complete implementation reference.

The 2024 RMIT-M paper will be the primary reference for the LLC converter design and implementation, as it shows the design methodology for designing the system using first harmonic approximation (FHA) and detailed transformer construction methods. The modular design approach is quite elegant from a testing perspective. Hence, a similar approach will be adopted for this implementation.

### 3 Conceptual Design

The proposed design for the APU is to begin with the LLC converter as two independent boards, which are then mechanically and electrically connected via the high-frequency transformer. This reflects the natural system boundaries between the high and low voltage sides while also improving the ability to perform sub-circuit testing following a similar approach to the 2024 RMIT-M paper.

### High Level Topology:

Interface (Undecided Connector)
LLC-HV - Tractive battery input (400-600V domain) (Unknown EMI) -----------------------------------------------------------------
EMI filter (Common-mode chokes) (Shunt Capacitors)
↓
Half Bridge Mosfets ← Half bridge Driver IC ← LLC Controller ← Optocoupler ↓
Resonant Tank Circuit
High Frequency Transformer (Primary) (400-600 HF AC)

=============================================
Ferrite Core (Magnetic & Structural Coupling) =============================================

LLC-LV - High Frequency transformer (Secondary) (12V AC) (Unknown Ripple) -----------------------------------------------------------------Synchronous Rectifier → Status MCU (STM32) ← Optocoupler
↓
Integrated battery (12 V) (Undecided Capacity) ← Isolated Charger -----------------------------------------------------------------LV-Interface (Undecided Connector) (12V Domain) (Unknown EMI)

This design follows the 2027 Formula SAE rules draft. It allows for a GLV system to operate independently of the tractive battery (EV.4.4.1). It also is galvanically isolated via magnetic coupling and optocouplers for signal routing (EV.7.5.1). It also avoids the same-board tractive system and GLV rule (EV.7.5.7) with two independent boards. However, for the optocouplers on the LLC-HV board, the area will be clearly marked and have a clearance distance of 3.0 mm and a creepage distance under conformal coating of 4.0 mm when operating at 300–600 VDC (EV 7.5.7).

The implementation plan is firstly to use planar finite element analysis to design the ferrite core transformer, and then design the LLC-HV board. The transformer will then be characterized, and an appropriate capacitor will be chosen. Then the LLC-HV board and transformer will be tested together with a dummy load. After that, the LLC-LV board will be made based on those testing results. The LLC-HV and LLC-LV boards will then be tested together and characterized, with the transient response helping to determine the capability of the APU-integrated battery. After which, the whole system will be packaged together as the LVG-APU and tested for EMI compliance, etc.

### 4 Project Management

The project will follow a waterfall-like project cycle, with each deliverable design leading into the next (within reason). The project deliverables consist of the LLC-HV and LLC-LV boards, the transformer, the LVG battery, and finally the APU package around those components.


Figure 3: Gantt chart showing the project timeline and deliverables

Rationale: The deliverables overlap, as the design phase of each defines enough information to begin development of the next. Given the timeframe of this project, the execution has to be concurrent. The “Ordering & Testing & Validation” blocks are due to the transient nature of procurement and safety reviews.

Similar to the project scope phase, the implementation work will be hosted on GitHub with code, documentation, and reference implementation within the repo. Engineering notes and design rationale will be within the repo issues. The repo follows the information scheme for issues (Appendix 2).

### 5 Conclusion

The LVG-APU for the R27 vehicle will be a first iteration of a new power system within the vehicle. The design arises from the architectural requirements of the LVG system, and the requirements formed arise from the current implementation and reference designs described in the literature review. The system consists of five deliverables: the LLC-HV and LLC-LV boards, the transformer, the LVG battery, and the APU packaging.

### 6 References

1. RMIT Motorsports, “A Customised Low-voltage Power Supply for a Formula SAE Electric Racing Vehicle”, Capstone Project, RMIT University, 2024.
2. RMIT Motorsports, “Innovative Actuation Systems for a Driverless Formula SAE Racing Car”, Capstone Project, RMIT University, 2021.
3. liv (rootthecause), “DCDC: An open source credit card sized DC/DC converter to convert up to 600 V to 24 V in an energy-, cost- and space-efficient way”, GitHub repository. Available: https://github.com/liv-instruments/dcdc
4. Formula SAE Rules, “2027 Formula SAE Rules”, SAE International, Draft, 2026.

### 7 Appendices

### 7.1 Appendix 1a: R26 LVG System Current Draw Estimation

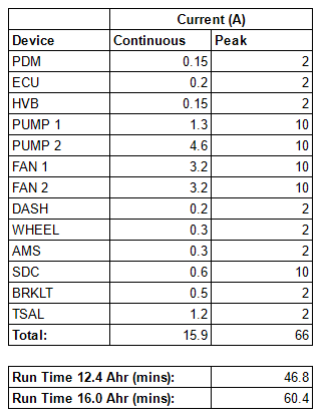
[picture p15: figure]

Figure 4: R26 LVG System Current Estimation

### 7.2 Appendix 1b: Current Density and Wire Diameter Model

# Calculate wire diameter across current density range at target power current_density = parameters.transformer.range.min_current_density

while current_density <= parameters.transformer.range.max_current_density: # Calculates the wire diameter based on target current & current density inner_term = 4 * target_current / (pi * current_density) secondary_wire_diameter = inner_term ** 0.5
primary_wire_diameter = secondary_wire_diameter / parameters.transformer. turns

# Saves parameters as raw values (kA/m^2, mm, mm) current_density_axis.append(current_density.stripped * 10 ** -3) primary_wire_diameter_axis.append(primary_wire_diameter.stripped * 10 ** 3) secondary_wire_diameter_axis.append(secondary_wire_diameter.stripped * 10 ** 3)

# Updates current density for next iteration

current_density += parameters.numerics.current_density

### 7.3 Appendix 2: GitHub Issue Labelling Scheme

LX | → Documentation and project structure
L0 | → Review and analysis of reference designs
L1 | → System level design, topology and interfaces
L2 | → Detailed design & prototyping
L3 | → Testing & Validation of prototype
DS | → De-scoped Feature, De-scoped Analysis
AC | → Architectural Change

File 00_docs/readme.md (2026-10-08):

### 00_docs

This README contains the series of deliverables and their associated write-ups. It also contains the internal resources, tags and application notes series.

---

#### [Scope](01_scope.pdf) — Project Scope

This document describes the scope of the project and outlines how the `LVG-APU` architecture was derived, 
along with the implementation plan.

---

#### Internal Resources

All internal documentation can be found within this repo's [`issues`](https://github.com/rmit-wgbowley/APU/issues).

#### Tags:

```
Project Progress:
----------------------------------------------------
LX -> Documentation and project structure
L0 -> Review and analysis of reference designs
L1 -> System level design, topology and interfaces
L2 -> Detailed design & prototyping
L3 -> Testing & validation of prototype
----------------------------------------------------
```

<br>

```
Miscellaneous:
----------------------------------------------------
DS  -> De-scoped feature, de-scoped analysis
AC  -> Architectural change
ES  -> Electrical systems
SD  -> System development / Architectural development
SIM -> Simulations & modelling
AN  -> Weekly application notes
----------------------------------------------------
```

#### Application Notes

```
0x0 = Week 0
0x1 = Week 1
0x2 = Week 2
0x3 = Week 3
0x4 = Week 4    <- Current State
0x5 = Week 5
0x6 = Week 6
0x7 = Week 7
0x8 = Week 8
0x9 = Week 9
0xA = Week 10
0xB = Week 11
0xC = Week 12
0xD = Week 13
0xE = Week 14
0xF = Week 15   <- Terminal State
```

> Check [`here`](https://github.com/rmit-wgbowley/APU/issues?q=is%3Aissue%20label%3AAN) to view the weekly application notes.

---

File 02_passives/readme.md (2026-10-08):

### 02_passives

#### [00_resonant_transformer](./00_resonant_transformer/readme.md) — Primary & Backup transformers

<div align="center">
  <table>
    <tr>
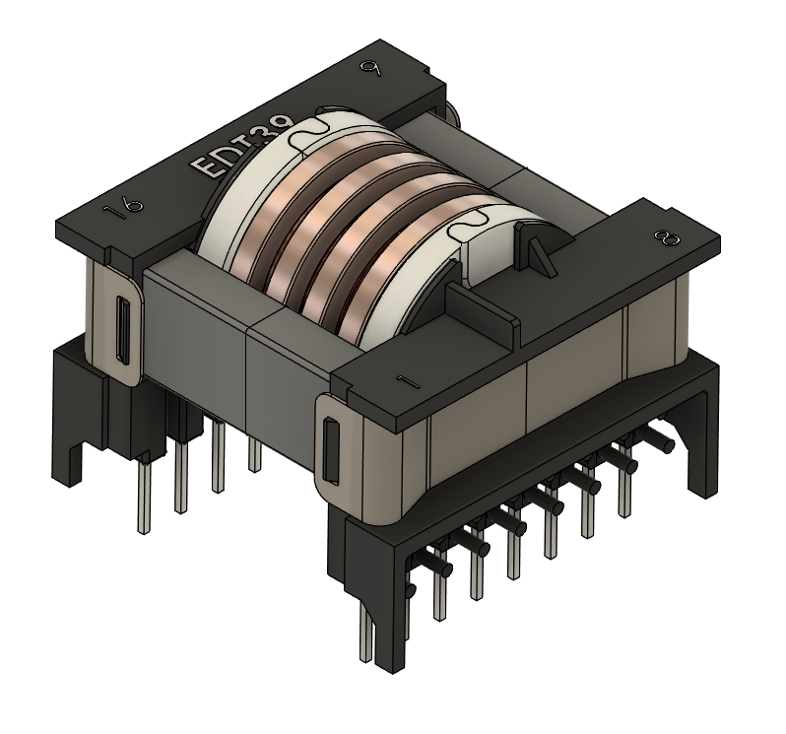
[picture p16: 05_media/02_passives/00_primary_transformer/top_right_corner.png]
Primary
      <td></td>
      <td>Backup</td>
    </tr>
    <tr>
      <td><em>Primary Transformer</em></td>
      <td><em>Backup Transformer</em></td>
    </tr>
  </table>
</div>

The resonant transformer forms part of the resonant tank circuit. 

---

#### [01_external_inductor](./01_external_inductor/readme.md) - External Inductor

<div align="center">
  <table>
    <tr>
      <td>External Inductor Side</td>
      <td>External Inductor Cross Section</td>
    </tr>
    <tr>
      <td><em>Top Right Side View</em></td>
      <td><em>Cross Sectional View</em></td>
    </tr>
  </table>
</div>

The external inductor allows for tuning of the resonant tank circuit via its self-inductance.

---

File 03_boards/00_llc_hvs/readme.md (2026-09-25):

### 00_llc_hvs

*(TBD) — Work in progress*

---

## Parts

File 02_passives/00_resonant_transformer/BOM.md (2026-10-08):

### Primary & Back-up Transformers — Bill of Materials (BOM)

| Status | Reference | Qty | Value | Footprint | Notes / Datasheet |
|---|---|-----|---|---|---|
| [-] | Core 1, Core 2 | 2 | B66364A2000X000 | TDK:ETD39_Core | Ferrite Core |
| [-] | Clamp 1 | 2 | B66364B1016T001 | TDK:ETD39_Clip | Coil Former Clip |
| [-] | Former 1 | 1 | B66363G0000X187 | TDK:ETD39_Former | Horizontal Coil Former |
| [x] | Core 3, Core 4 | 2 | B66366A2000X000 | TDK:ETD44_Core | Ferrite Core |
| [x] | Clamp 2 | 2 | B66366B1018T001 | TDK:ETD44_Clip | Coil Former Clip |
| [x] | Former 2 | 1 | B66365G0000X187 | TDK:ETD44_Former | Horizontal Coil Former |
| [ ] | Litz 2 | 1 | 64/38LITZ.125 | Wire:Litz_Rectangular | Primary Litz Wire |
| [ ] | Litz 1 | 1 | 650/42LITZ.125 | Wire:Litz_Rectangular | Secondary Litz Wire |
| [ ] | Sleeve 1 | 1 | STFE 20 CLR | N/A | PTFE Primary Sleeve | 
 
> *(Note). `[ ]` Not Ordered. `[-]` Not Required. `[x]` Ordered.*

---

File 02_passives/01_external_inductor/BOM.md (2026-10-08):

### External Inductor — Bill of Materials (BOM)

| Status | Reference | Qty | Value | Footprint | Notes / Datasheet |
|---|---|-----|---|---|---|
| [-] | Clamp | 2 | B65812A2203X000 | TDK:RM8_Clamp | Vertical Core Clamp | 
| [-] | Former  | 1 | B65812N1008D001 | TDK:RM8 | Vertical Coil Former |
| [-] | Core | 2 | B65811J0400A087 | TDK:RM8 | Vertical Ferrite Core Sections | 
| [-] | Sleeve 1 | 1 | STFE 20 CLR | N/A | PTFE Sleeve | 
| [ ] | Litz 2 | 1 | 64/38LITZ.125 | Wire:Litz_Rectangular | Litz Wire |

> *(Note). `[ ]` Not Ordered. `[-]` Not Required. `[x]` Ordered.*

---

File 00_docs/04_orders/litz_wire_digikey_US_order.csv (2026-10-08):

Index | Quantity | Part Number | Manufacturer Part Number | Description | Unit of Measure | Customer Reference | Available | Backorder | Unit Price | Extended Price USD
1 | 1 | 2328-650/42LITZ.125-ND | 650/42LITZ.125 | MAGNET WIRE 14 AWG 3 METER |  |  | 1 | 0 | 48.28000 | $48.28
2 | 1 | 2328-64/38LITZ.125-ND | 64/38LITZ.125 | MAGNET WIRE 20 AWG 11.9 METER |  |  | 1 | 0 | 37.60000 | $37.60

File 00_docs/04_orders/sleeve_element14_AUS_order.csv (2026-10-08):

Line No. | Order Code | RoHS Compliant? | Customer Reference No | Notes | Qty | Mfr Part No | Manufacturer Name | Manufacturer / Description | Availability | Unit Price (excl GST) ($) | Line Price (excl GST) ($) | Discount Price ($)
1 | 1191043 | RoHS: YES / PHTHALATES: YES |  |  | 1.0 | STFE 20 CLR | MULTICOMP PRO | MULTICOMP PRO Sleeving, Protective, PTFE (Polytetrafluoroethylene), Transparent, 0.97 mm, 5 m, 16.4 ft | 344 | 10.1700 | 10.17
 |  |  |  |  |  |  | Sub Total | $10.17
 |  |  |  |  |  |  | Goods Total | $10.17
 |  |  |  |  |  |  | Delivery | $0.00
 |  |  |  |  |  |  | GST | $1.02
 |  |  |  |  |  |  | Total | $11.19

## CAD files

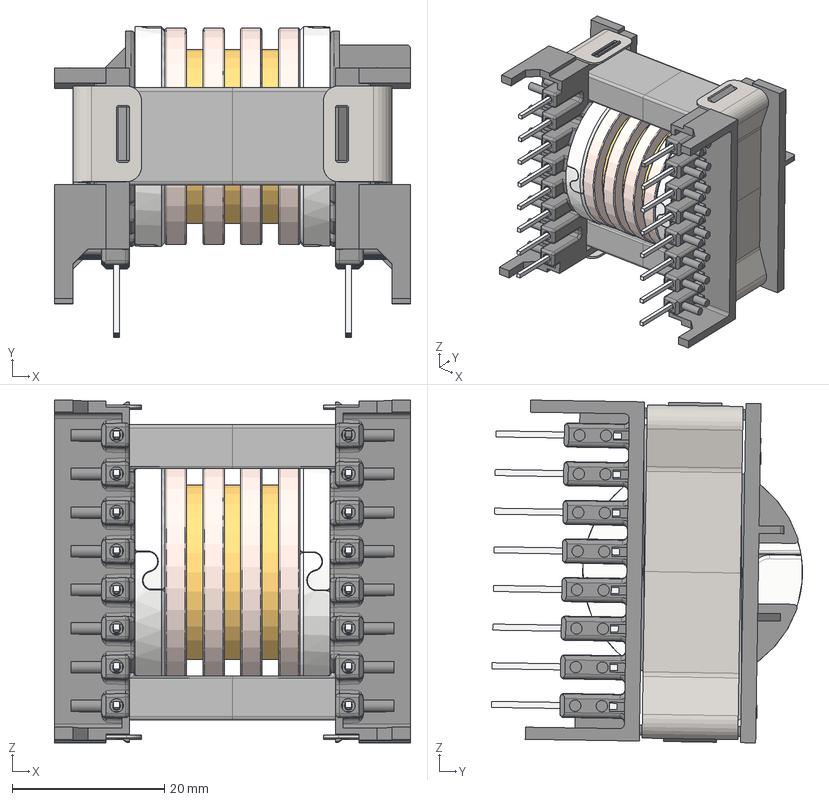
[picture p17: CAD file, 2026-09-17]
02_passives/00_resonant_transformer/03_mechanical/primary_transformer.step
46.8 x 40.9 x 45.1 mm
ETD39 Core x 2
ETD39 Yoke x 2
ETD39 Former
spacers x 2
Secondary x 2
tertiary x 2
tape_layer_3
layer_3
tape_layer_2
layer_2
tape_layer_1
layer_1

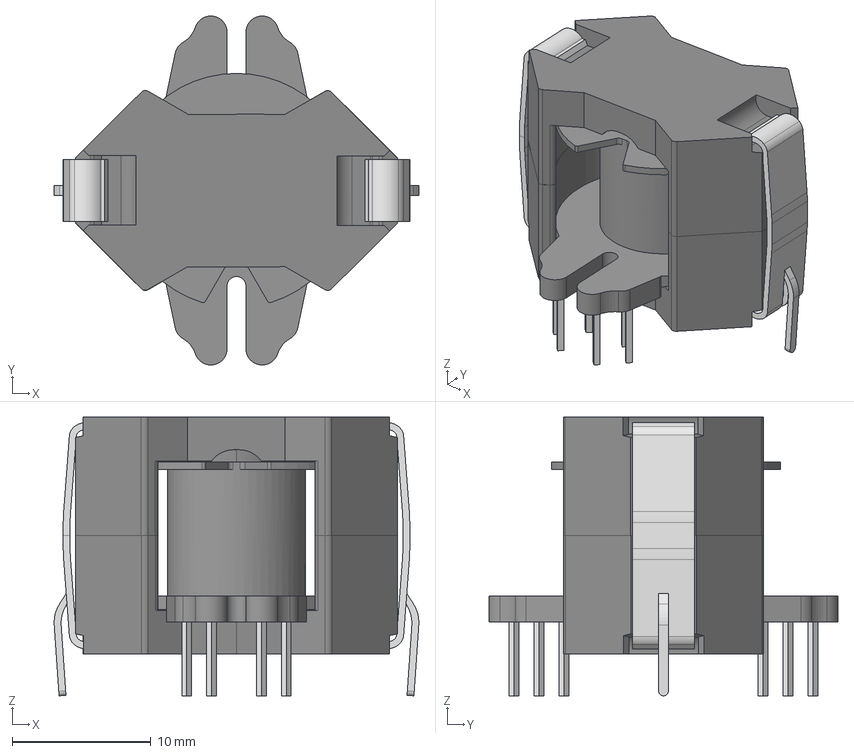
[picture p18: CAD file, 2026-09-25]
02_passives/01_external_inductor/03_mechanical/external_inductor.step
26.3 x 25.2 x 20.1 mm
RM8_bobbin
RM8_ferrite_B x 2
RM8_clip x 2
RM8_pin x 12

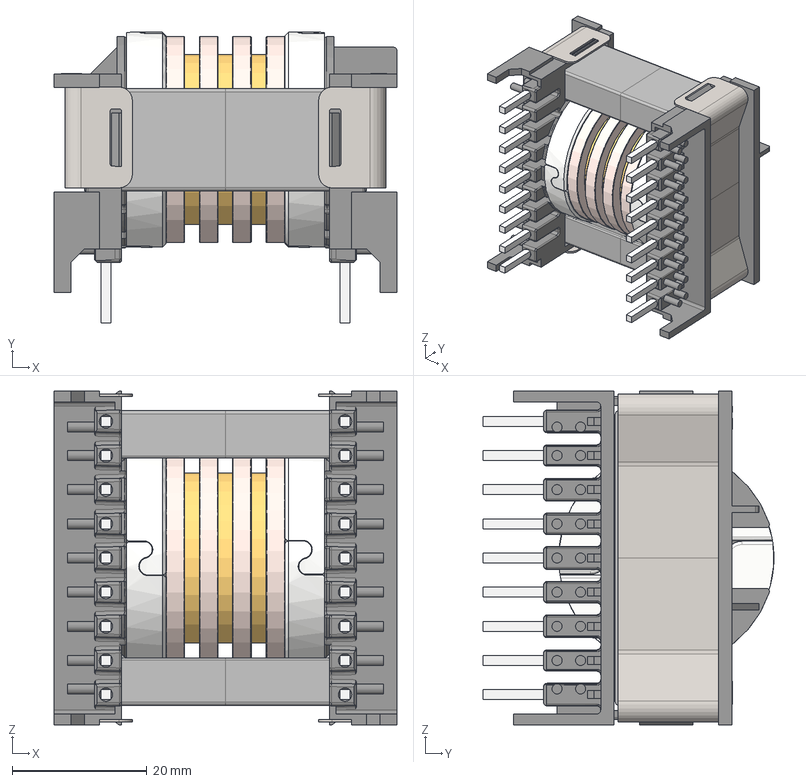
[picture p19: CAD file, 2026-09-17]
02_passives/00_resonant_transformer/03_mechanical/backup_transformer.step
51.0 x 43.2 x 49.6 mm
ETD44 Coilformer
ETD44 Core x 2
ETD44_Yoke x 2
spacers x 2
tape_layer_1
tape_layer_2
tape_layer_3
tertiary x 2
secondary x 2
layer_1
layer_2
layer_3

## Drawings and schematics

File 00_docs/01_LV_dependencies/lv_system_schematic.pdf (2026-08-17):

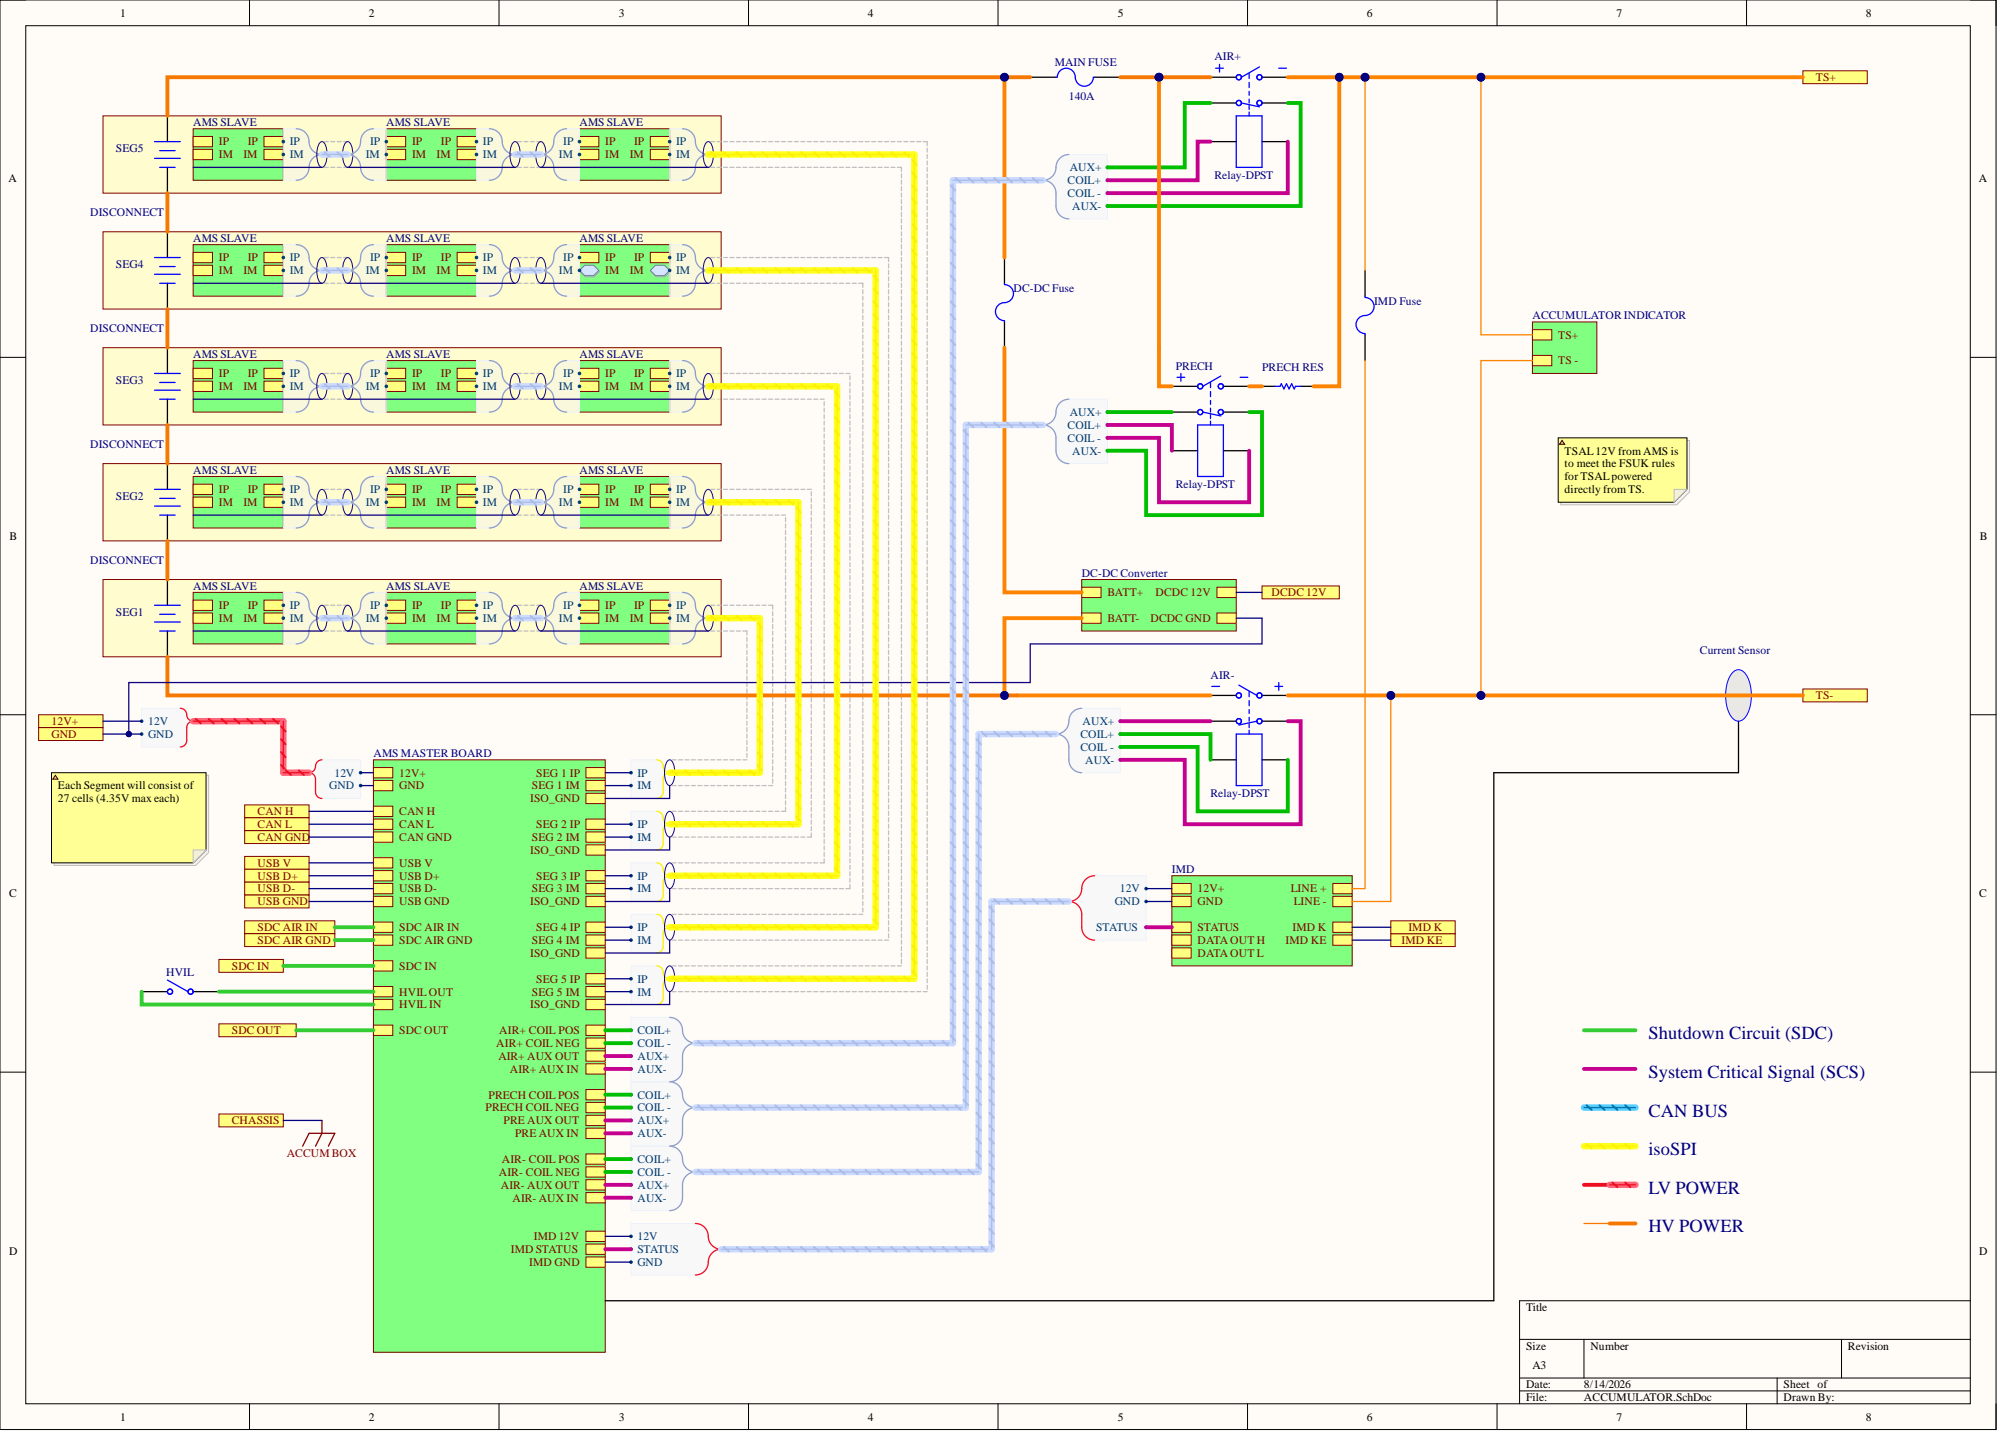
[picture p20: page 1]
AIR IN; SDC IN; IMD ST; VIL IN; AMS MAST; HV POWER; nal (SCS); PRECH RES; ACCUM BO; 12V GND; t Sen; AMS SL; MAIN FUSE 140A; IMD Fu; V from; o meet; he FSU; y from; Each Segmen; 7 cel; V max each

COIL - AUX+ AUX-
COIL

BAT

AIR+ COIL PO
AIR+ COIL N
AIR+

own Circuit (SDC)

System Critical Sig

PRECH COIL PO
PRECH COIL
PRE

COIL+

CAN BUS LV POWER

AIR- COIL PO
AIR- COIL N
AIR-

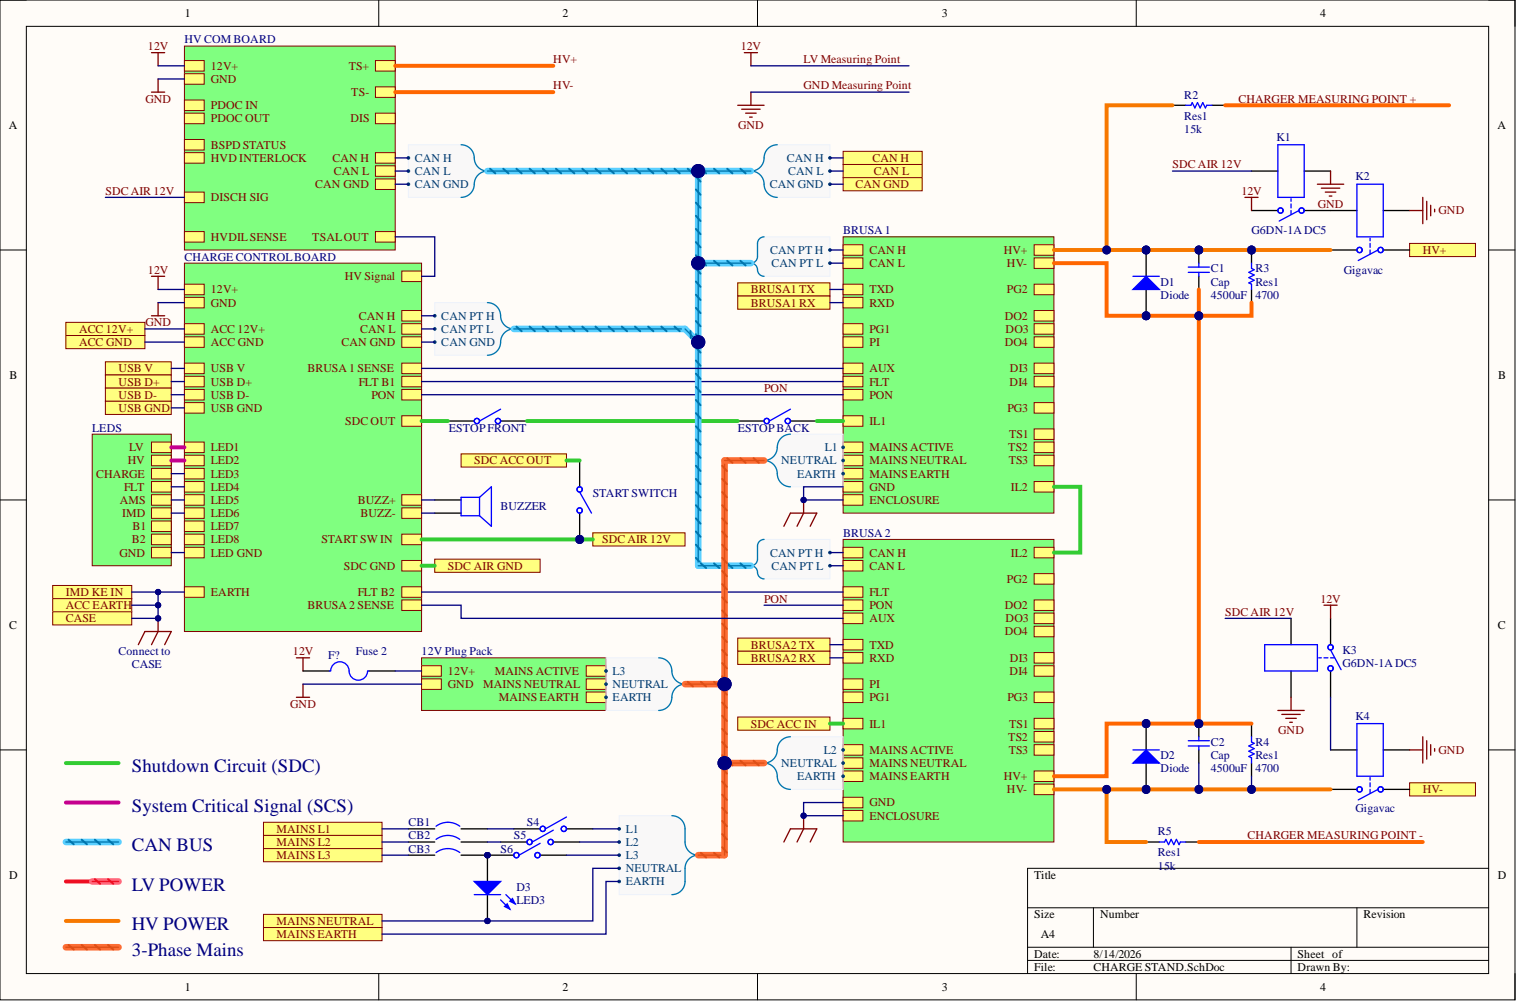
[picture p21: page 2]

PON

ESTOP FRONT | L1

System Critical Signal (SCS)

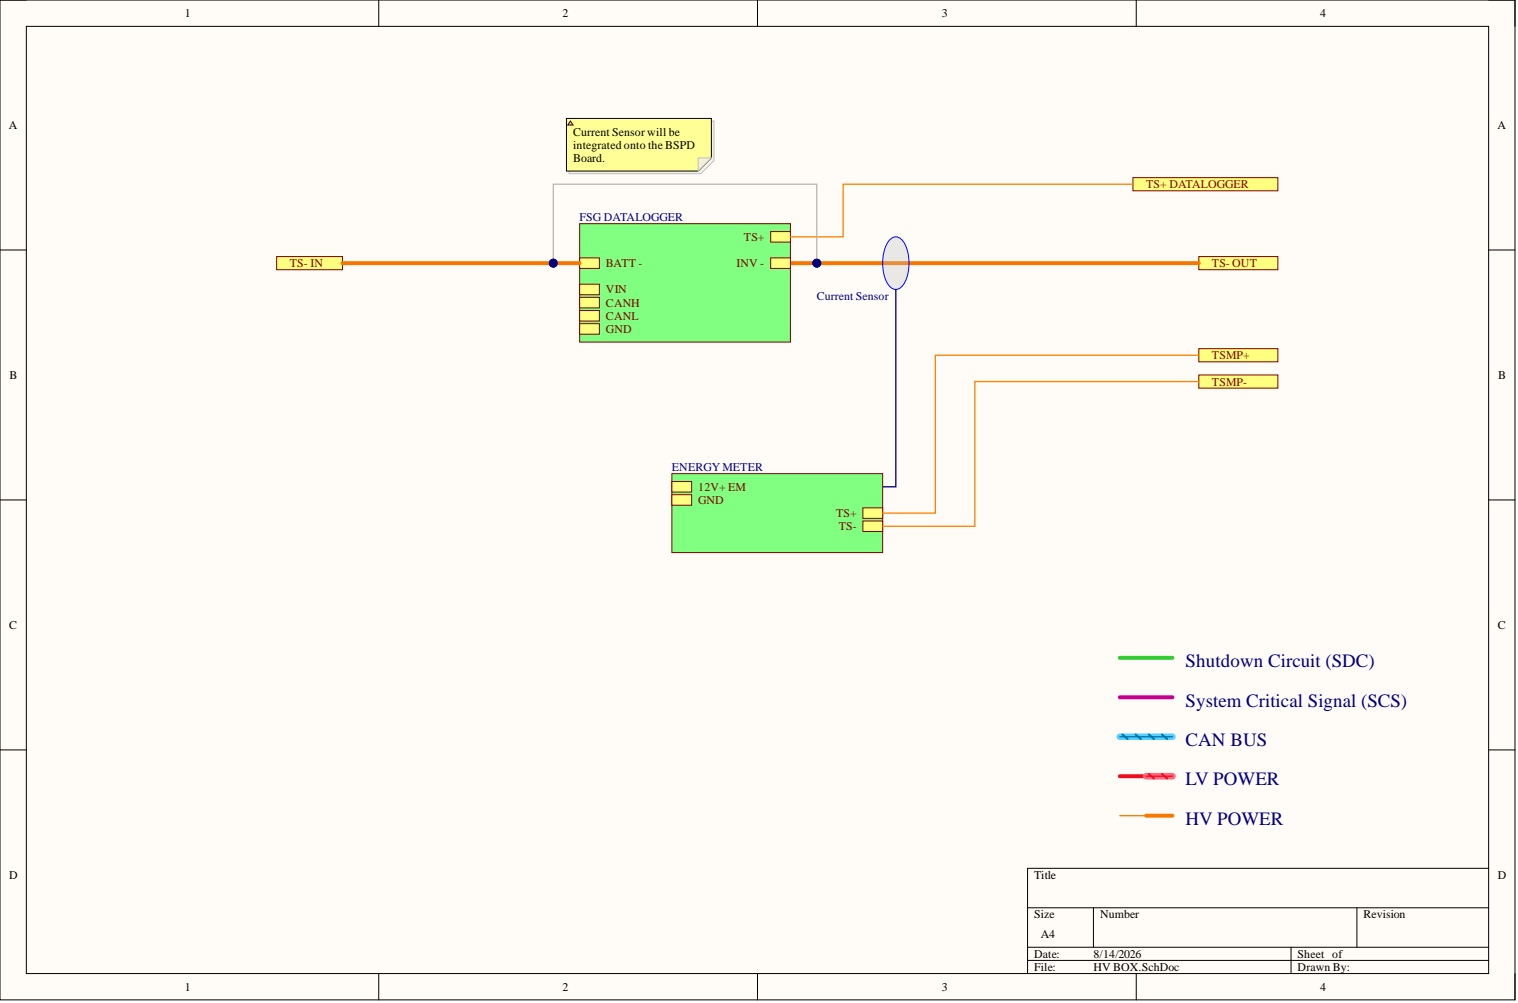
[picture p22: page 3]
File:; HV BOX.SchDoc; Drawn By:; TS- OUT; CAN BUS; LV POWER; HV POWER; Current Sensor; ENERGY METER; BATT -; INV -; FSG DATALOGGER; TS+ DATALOGGER; POTS0 IN; POTS0 OUT; POTS0 DATALOGGER

Current Sensor will be
integrated onto the BSPD
Board.

Shutdown Circuit (SDC)

System Critical Signal (SCS)

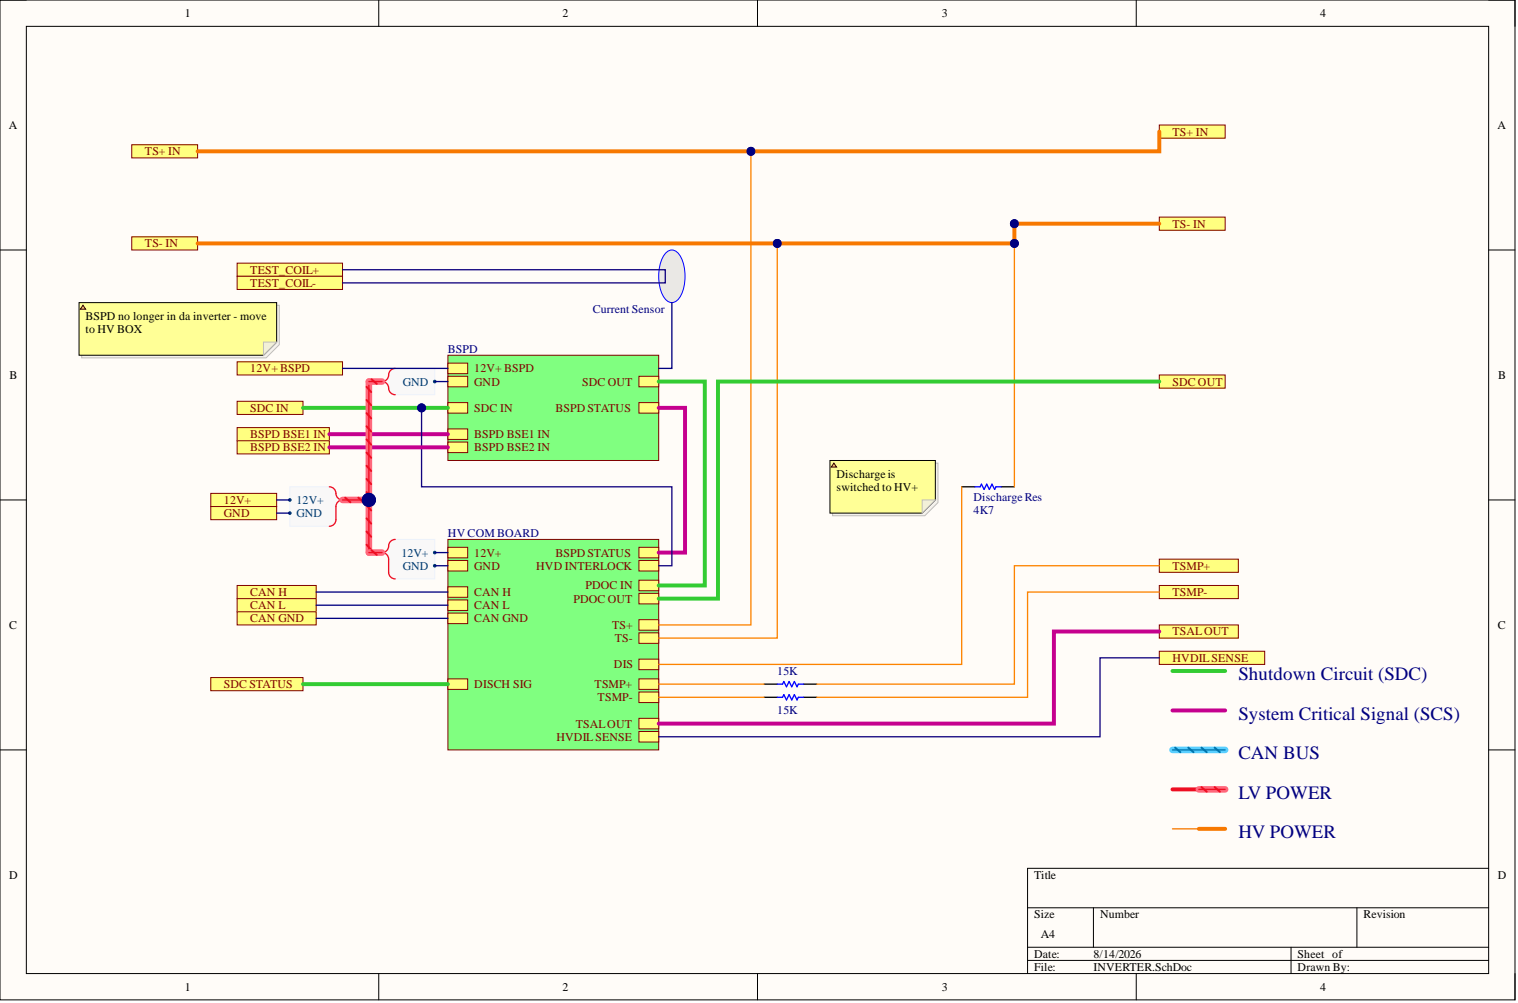
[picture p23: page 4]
File:; INVERTER.SchDoc; Drawn By:; SDC IN; SDC OUT; 12V+ BSPD; BSPD STATUS; BSPD BSE1 IN BSPD BSE2 IN; Current Sensor; HVDIL SENSE; CAN H CAN L CAN GND; DISCH SIG; HVD INTERLOCK; PDOC IN PDOC OUT; HV COM BOARD; BSPD BSE1 IN; SDC STATUS; Discharge Res; CAN BUS; LV POWER; HV POWER; BSPD BSE2 IN; PIR601 COR6; PIR602; PIR701 COR7; PIR702; PIR801; PIR802 COR8; PO12V0 BSPD; POBSPD BSE1 IN POBSPD BSE2 IN; POCAN GND; POCAN H POCAN L; POSDC STATUS; POSDC IN; POHVDIL SENSE; POTS0 IN; POSDC OUT; POTSAL OUT

BSPD no longer in da inverter - move
to HV BOX

Discharge is
switched to HV+

Shutdown Circuit (SDC)

System Critical Signal (SCS)

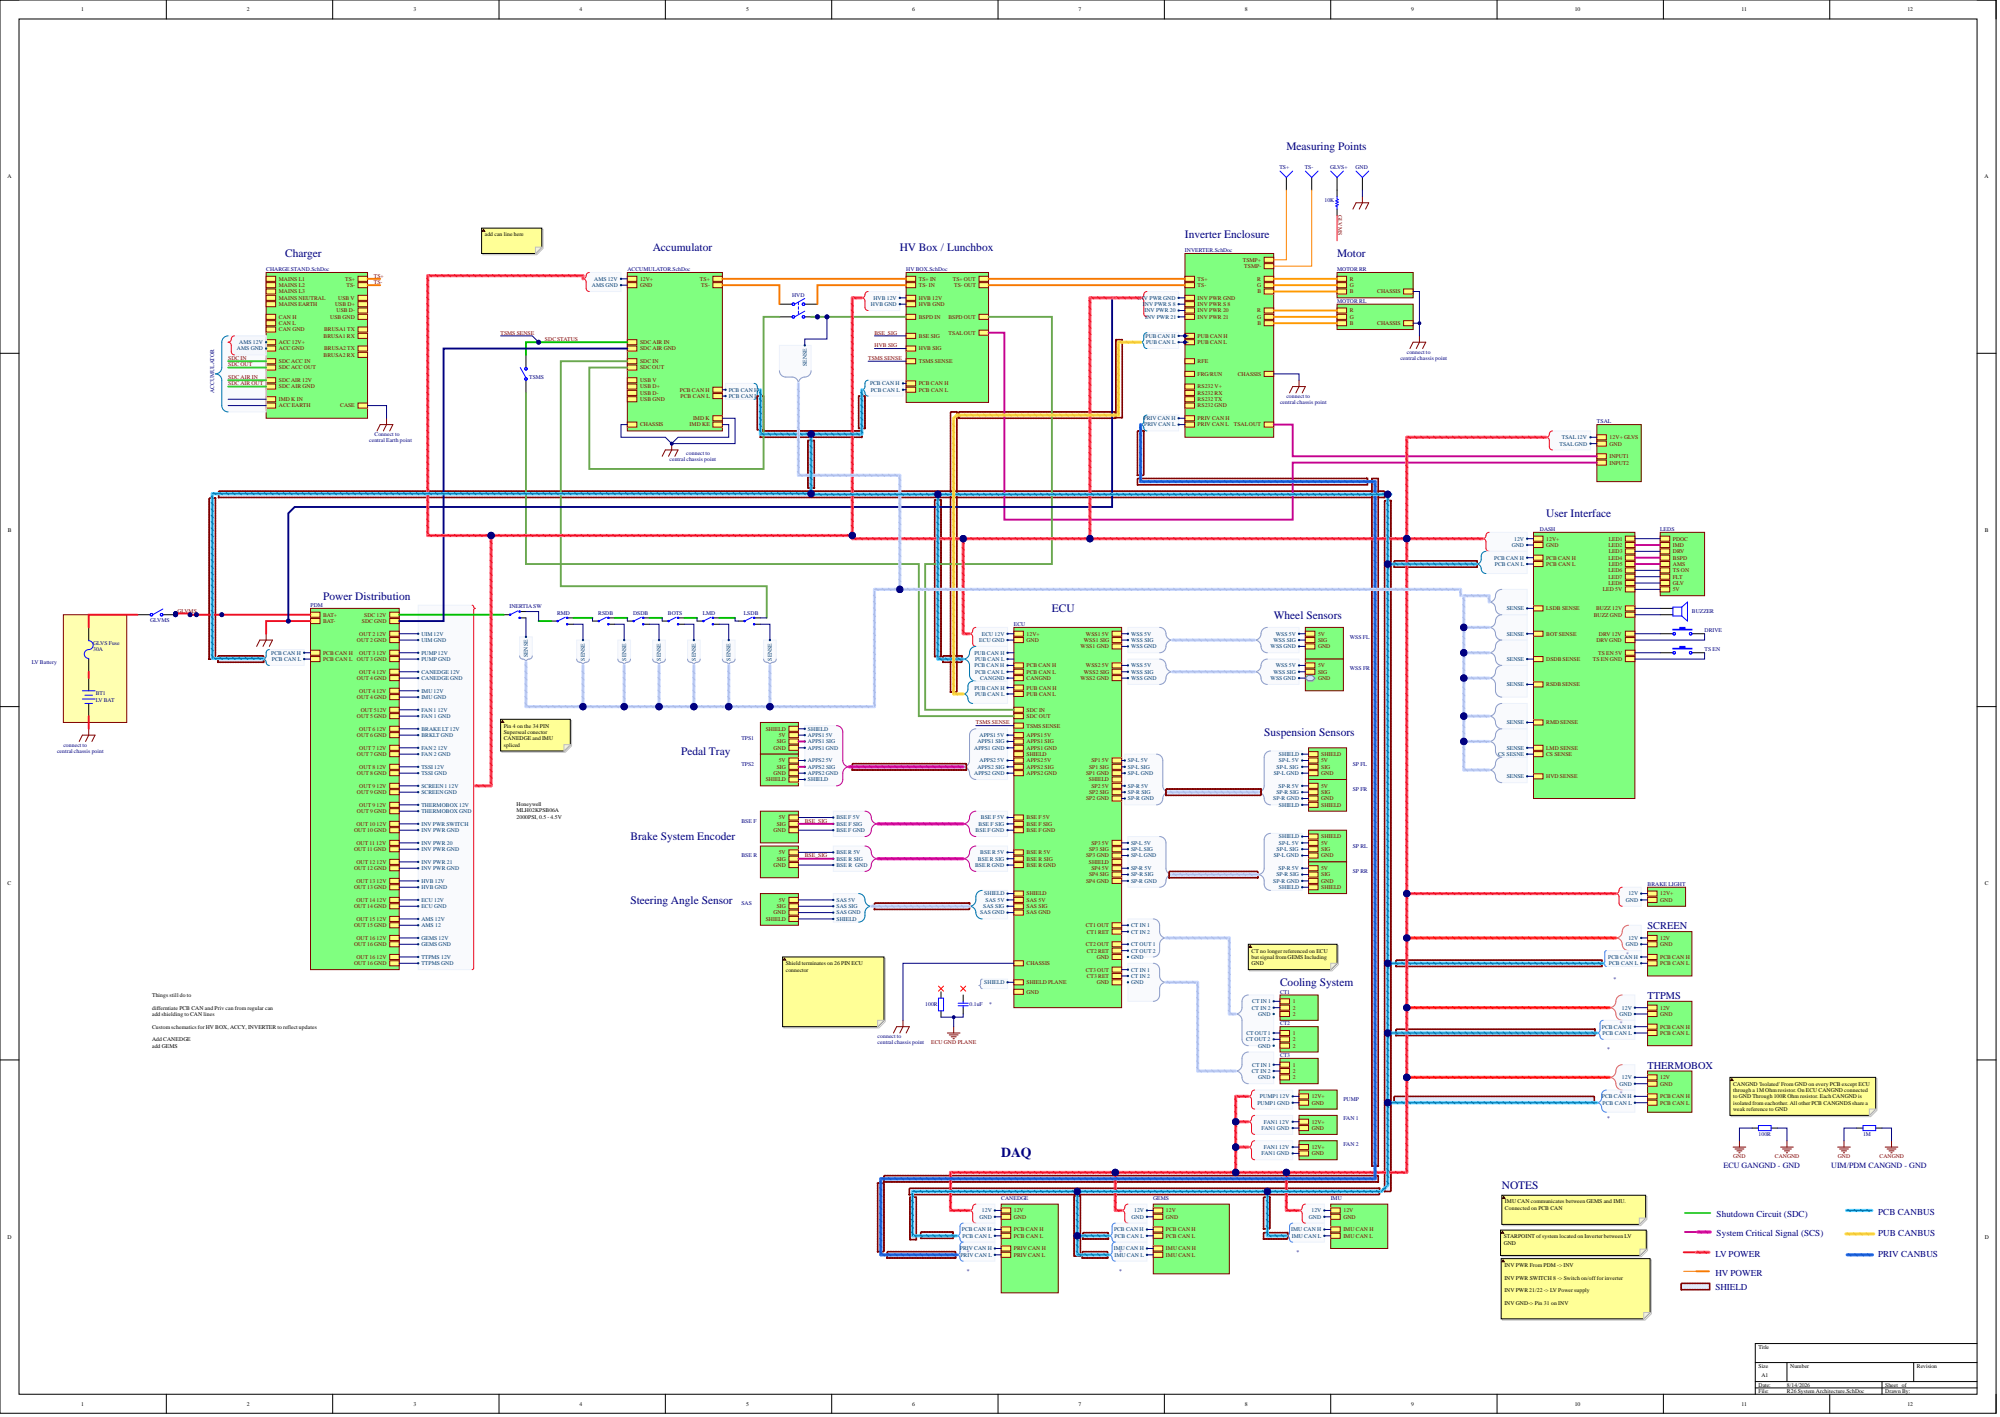
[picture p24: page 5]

add can line here

Pin 4 on the 34 PIN
Superseal conector
CANEDGE and IMU
spliced

CT no longer referenced on ECU
but signal from GEMS Including
GND
Cooling System

Shield terminates on 26 PIN ECU
connector

Things still do to

differntiate PCB CAN and Priv can from regular can
add shielding to CAN lines

Custom schematics for HV BOX, ACCY, INVERTER to reflect updates

CANGND 'Isolated' From GND on every PCB except ECU
through a 1M Ohm resistor. On ECU CANGND connected
to GND Through 100R Ohm resistor. Each CANGND is
isolated from eachother. All other PCB CANGNDS share a
weak reference to GND

IMU CAN communicates between GEMS and IMU.
Connected on PCB CAN

System Critical Signal (SCS)

STARPOINT of system located on Inverter between LV

INV PWR From PDM -> INV

INV PWR SWITCH 8 -> Switch on/off for inverter

INV PWR 21/22 -> LV Power supply

INV GND-> Pin 31 on INV

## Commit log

2026-08-01 Rootthecause schematic & infineon llc design
2026-08-06 Power usage program and few references
2026-08-10 Added transfer gain vs input voltage and removed sampling rate
2026-08-17 Setup for detailed power analysis and initial setup for .tex scope file
2026-08-20 Added the required Galvanic isolation for the external charger
2026-09-17 Week 0x1 | Transformer Design is Meh!? (#26)
    * Initial transformer file system
    * Added comments to .FEM files.
    * Transformer saturation model.
    * Calculating inductance and added hand book for transformer design
    * Added modelling for the transformer
    * Removed misleading figure
    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
    [backup_transformer.step, primary_transformer.step]
2026-09-23 Added images for external inductor & other stuff
    [RM8S.step]
2026-09-23 Added referencing for the new boards.
2026-09-25 Finished 02_passives area.
    [external_inductor.step]
2026-09-25 Added the note for the LLC boards.
2026-09-25 Initial start on the LLC boards
    [main.SchDoc]
2026-10-08 Week 0x3 | LLC-HVS board development :) (#31)
    * Week_0x2 | Finishing Passives & Beginning LLC Board Development
    * Updating routing & adding reference material for llc-hvs
    * Removing placeholders for now.
    * More updates & fixed transformer wire
    * Update README.md
    * Few more fixes.
    * Bit more details.
    * Update README.md
    * Update README.md
    * Update README.md
    * Update README.md
    * Update README.md
    * Update README.md
    * Update README.md
    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
    [litz_wire_digikey_US_order.csv, main.SchDoc, sleeve_element14_AUS_order.csv]
2026-10-14 Updates to readme & Rmcybernetics Litz Wire (#34)
    * Updates to the transformer section
    * Inductor
    * More updates
    * Added simulation section
    * Update readme.md
    * Added bibtex
    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
